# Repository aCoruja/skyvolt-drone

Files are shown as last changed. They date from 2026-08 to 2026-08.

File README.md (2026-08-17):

<div align="center">

# SkyVolt

**Drone medidor e fiscalizador de ambientes de alta e baixa energia**

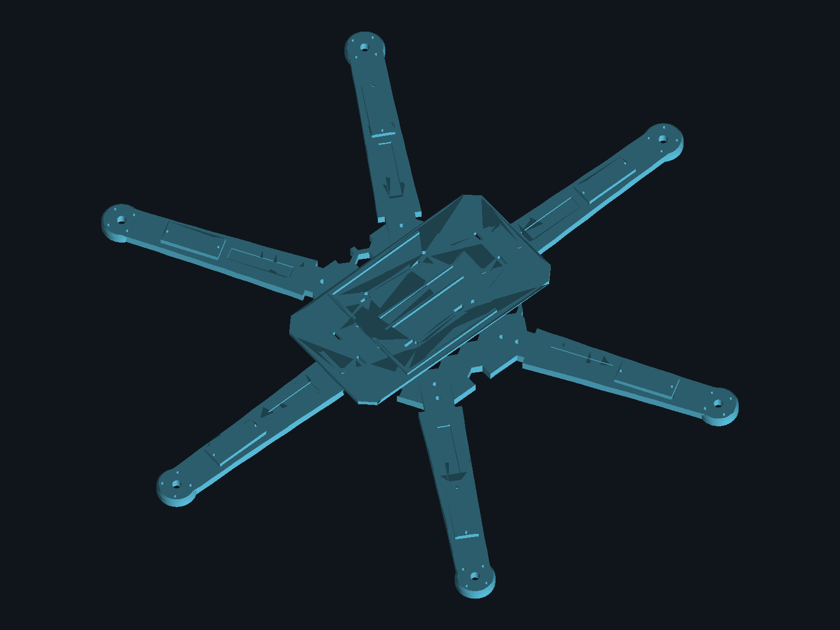
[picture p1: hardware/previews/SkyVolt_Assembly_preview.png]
Preview do hexacóptero SkyVolt montado


</div>

Hexacóptero de estrutura impressa em 3D cuja função principal é medir tensão e corrente elétrica em pontos de um ambiente controlado, classificar automaticamente o tipo de circuito (AC/DC, faixa de tensão) e reportar os dados a um aplicativo desktop de controle e monitoramento em tempo real via LoRa.

Projeto da disciplina 34943 — Desenvolvimento de Aplicações Computacionais (tema-base: Monitor de Consumo e Qualidade de Energia / Smart Grid), usando o SkyVolt como o protótipo físico opcional permitido pelo enunciado. Documento completo de requisitos, arquitetura e BOM em [`docs/SkyVolt_Documento.pdf`](docs/SkyVolt_Documento.pdf); Roadmap do semestre (14/08 a 02/12/2026) em [`ideias/roadmap.md`](ideias/roadmap.md); devolutivas das entregas em [`avaliacoes/`](avaliacoes/).

## Equipe

<!-- preencher com nome + usuário GitHub de cada integrante antes da entrega A1/1 — é critério de nota (governança/git) -->
- Matheus Dapper ([@aCoruja](https://github.com/aCoruja))
- _Vitória Aparecida Vendausen([@Viihvendausen](https://github.com/Viihvendausen)_

- _Sophia Gama de Moura ([@Sophthe141](https://github.com/Sophthe141))_

## Estrutura do repositório

```
README.md       este arquivo — visão geral, equipe e estado do projeto
docs/           documentos técnicos: requisitos, arquitetura e BOM (fonte .tex + PDF gerado),
                requisitos funcionais do app desktop
ideias/         planejamento e acompanhamento de ideias — o que o time PLANEJA fazer, semana a semana
avaliacoes/     devolutivas oficiais do professor por entrega — nota, feedback, pontos a corrigir
hardware/       projeto mecânico (CAD paramétrico FreeCAD, STL/STEP para impressão 3D)
  frame/        peças atuais — hub, braço (x6) e bandeja de eletrônica
  legacy/       versão anterior do frame (peça única), mantida como referência
  previews/     renders das peças
firmware/       código dos dois ESP32 (voo/FPV e telemetria/LoRa) — a especificar
app/            aplicativo desktop de controle e monitoramento — a especificar
notebooks/      prototipagem e análise de dados (calibração de sensores, protocolo LoRa, etc.)
```

`ideias/` e `avaliacoes/` são complementares: um documenta o planejamento, o outro o resultado real de cada entrega — mantidos junto ao roadmap para não perder o histórico de evolução da nota ao longo do semestre.

## Estado atual (Rev. 1.3 do documento)

- Requisitos, arquitetura e BOM fechados.
- Frame mecânico redesenhado em 3 peças modulares (hub + braço ×6 + bandeja de eletrônica), validado para impressora de mesa 220×220mm, motor brushless RS1606 3300KV com verificação de empuxo e autonomia.
- Firmware, aplicativo desktop e carcaças dos efetuadores ainda não iniciados — ver Seção 8 (Pendências) do documento.

## Peças (impressão 3D)

Gerado pelo script paramétrico [`skyvolt_frame.py`](hardware/frame/skyvolt_frame.py) (FreeCAD). Arquivos `.stl`/`.step`/`.FCStd` em [`hardware/frame/`](hardware/frame/).

<div align="center">
<table>
<tr>
<td align="center" width="33%">
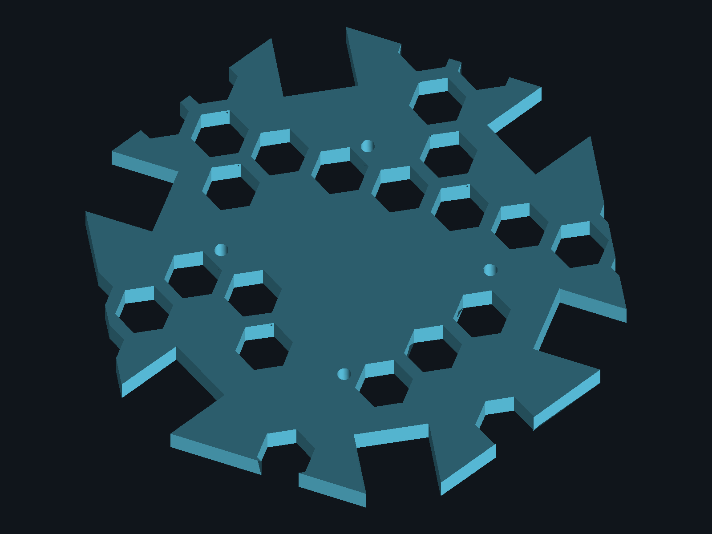
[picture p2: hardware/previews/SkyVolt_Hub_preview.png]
<br>
<b>Hub</b> — 1× — 129,6×121,2mm
</td>
<td align="center" width="33%">
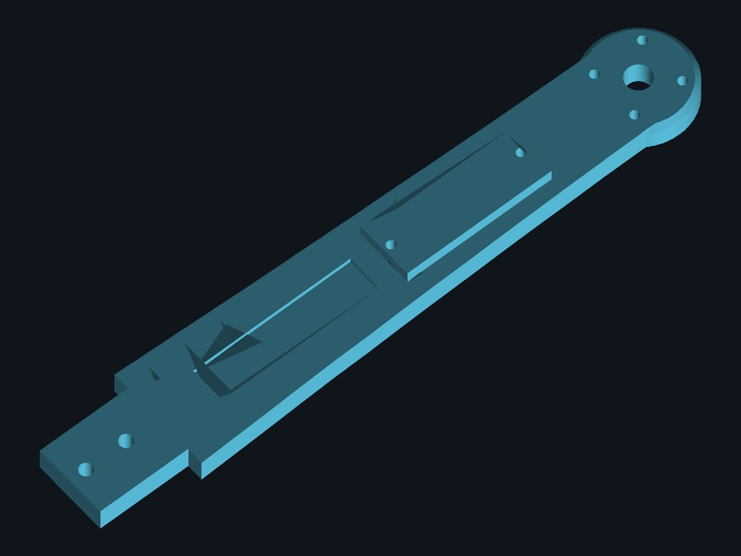
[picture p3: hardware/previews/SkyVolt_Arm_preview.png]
<br>
<b>Braço</b> — 6× — 154×26mm
</td>
<td align="center" width="33%">
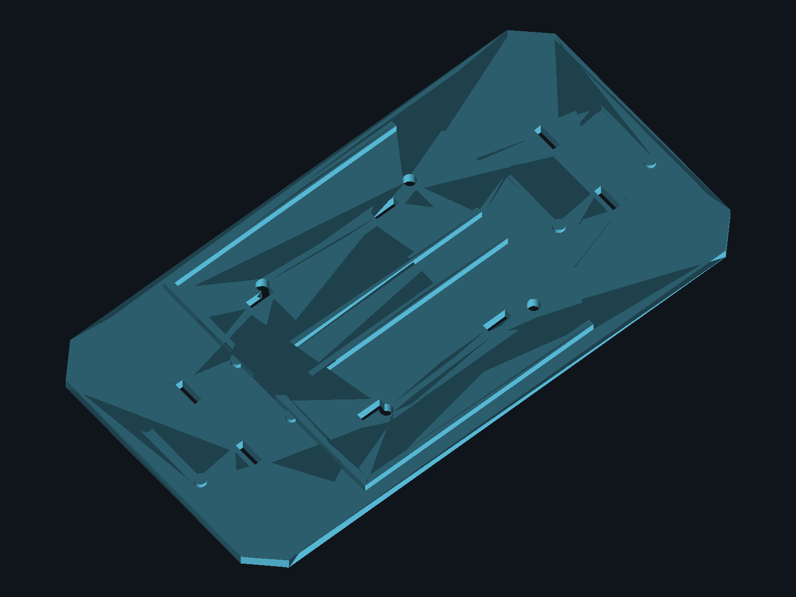
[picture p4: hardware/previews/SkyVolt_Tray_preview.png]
<br>
<b>Bandeja de eletrônica</b> — 1× — 150×80mm
</td>
</tr>
</table>
</div>

Todas as peças cabem numa mesa de impressão de 220×220mm. Hub e braço se unem por encaixe lingueta/rasgo + 2 parafusos M3 por junta; motor RS1606 3300KV (pad 12×12mm/4×M2); braço já sai com base de fixação para servo SG90.

## Utilização de IA

A utilização de IA foi realizada de forma educativa e colaborativa, com fins de estudo. A ferramenta não foi utilizada para resolver os problemas sem a aplicação de raciocínio lógico e compreensão por parte dos autores.

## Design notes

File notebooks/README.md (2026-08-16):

# Notebooks

Prototipagem e análise exploratória que não pertence ao firmware/app final: calibração de sensores (clamp de corrente, EMF, Hall/shunt), validação do protocolo de mensagens LoRa, análise de dados de bancada do motor/hélice, etc.

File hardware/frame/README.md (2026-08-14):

# Frame — peças atuais (Rev. 1.3)

<div align="center">
Montagem do frame SkyVolt
</div>

3 peças impressas separadamente, todas dentro da mesa de impressão de 220×220mm:

| Peça | Arquivo | Qtd | Dimensões |
|---|---|---|---|
| Hub | `SkyVolt_Hub.stl` | 1 | 129,6×121,2mm |
| Braço | `SkyVolt_Arm.stl` | 6 | 154×26mm |
| Bandeja de eletrônica | `SkyVolt_Tray.stl` | 1 | 150×80mm |

Gerado pelo script paramétrico `skyvolt_frame.py` (FreeCAD, `freecad.cmd skyvolt_frame.py`). `SkyVolt_Assembly_Preview.*` é só visualização (hub + 6 braços + bandeja posicionados), não é peça de impressão.

Hub e braço se unem por encaixe lingueta/rasgo + 2 parafusos M3 por junta. Motor: RS1606 3300KV, pad com padrão de furação 12×12mm/4×M2 (assumido para a classe do motor — confirmar contra datasheet real antes de imprimir em lote, ver Seção 8 do documento). Braço já sai com base de fixação para servo SG90 (M2, 32,5mm de espaçamento). Bandeja carrega 2×ESP32-S3 (trilho dimensionado para o footprint oficial 70×28mm) e 2×módulo LoRa (baia genérica por abraçadeira, footprint do módulo ainda não confirmado).

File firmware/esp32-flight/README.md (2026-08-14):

# ESP32 #1 — Voo / FPV

Responsável por vídeo de navegação (FPV) e comandos de voo via WiFi, baixa latência. Troca heartbeat por fio com o ESP32 #2 (telemetria/supervisor de segurança).

Código ainda não iniciado — ver Seção 4.3 e Seção 8 (Pendências) de `docs/SkyVolt_Documento.pdf`.

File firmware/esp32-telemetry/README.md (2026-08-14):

# ESP32 #2 — Telemetria / LoRa / Supervisor de segurança

Responsável pela telemetria de sensores via LoRa (tensão, corrente, classificação AC/DC, modo utilizado) e pela máquina de failsafe. Câmera e fonte de energia independentes do ESP32 #1.

Código ainda não iniciado — ver Seção 4.3 e Seção 8 (Pendências) de `docs/SkyVolt_Documento.pdf`.

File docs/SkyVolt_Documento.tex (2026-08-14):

\documentclass[11pt,a4paper]{article}

% ---------- PACOTES ----------
\usepackage[utf8]{inputenc}
\usepackage[T1]{fontenc}
\usepackage[brazilian]{babel}
\usepackage{lmodern}
\usepackage[a4paper,margin=2.3cm,top=2.6cm,bottom=2.8cm,headheight=22pt]{geometry}
\usepackage{xcolor}
\usepackage{colortbl}
\usepackage{booktabs}
\usepackage{longtable}
\usepackage{array}
\usepackage{tikz}
\usepackage{titlesec}
\usepackage{enumitem}
\usepackage{fancyhdr}
\usepackage{microtype}
\usepackage{hyperref}
\usepackage{textcomp}

% ---------- PALETA ----------
\definecolor{voltnavy}{HTML}{10151B}
\definecolor{voltcyan}{HTML}{1F6F8F}
\definecolor{voltcyanlight}{HTML}{5BC2E0}
\definecolor{voltcopper}{HTML}{B5652F}
\definecolor{voltamber}{HTML}{9A640C}
\definecolor{voltamberbg}{HTML}{F3E6CD}
\definecolor{voltok}{HTML}{2E6B4C}
\definecolor{voltokbg}{HTML}{DFEEE6}
\definecolor{voltpending}{HTML}{5B5F82}
\definecolor{voltgray}{HTML}{4D5A63}
\definecolor{voltrule}{HTML}{CDD4D9}
\definecolor{voltbandbg}{HTML}{EEF1F2}

\hypersetup{
  colorlinks=true,
  linkcolor=voltcyan,
  urlcolor=voltcyan,
  citecolor=voltcyan,
  pdftitle={SkyVolt - Documento de Requisitos, Arquitetura e BOM},
  pdfsubject={Drone medidor e fiscalizador de ambientes de alta e baixa energia}
}

% ---------- TIPOGRAFIA DE SEÇÕES ----------
\titleformat{\section}
  {\Large\bfseries\color{voltcyan}}
  {\thesection}{0.6em}{}
\titlespacing*{\section}{0pt}{1.6em}{0.9em}

\titleformat{\subsection}
  {\large\bfseries\color{voltcopper}}
  {\thesubsection}{0.6em}{}
\titlespacing*{\subsection}{0pt}{1.2em}{0.6em}

\renewcommand{\contentsname}{Sumário}

% ---------- CABEÇALHO/RODAPÉ ----------
\pagestyle{fancy}
\fancyhf{}
\renewcommand{\headrulewidth}{0.4pt}
\renewcommand{\headrule}{\hbox to\headwidth{\color{voltrule}\leaders\hrule height \headrulewidth\hfill}}
\fancyhead[L]{\footnotesize\ttfamily\color{voltgray} SkyVolt}
\fancyhead[R]{\footnotesize\ttfamily\color{voltgray} Requisitos \& Arquitetura}
\fancyfoot[C]{\footnotesize\ttfamily\color{voltgray} \thepage}

% ---------- COMANDOS AUXILIARES ----------
\newcommand{\specline}[2]{{\ttfamily\footnotesize\color{voltcyanlight}#1}\hfill{\normalsize\color{white}#2}\\[0.4em]}
\newcommand{\statusok}{\textcolor{voltok}{\textbf{decidido}}}
\newcommand{\statuspend}{\textcolor{voltpending}{\textbf{pendente}}}
\newcommand{\statushaz}{\textcolor{voltamber}{\textbf{limitação}}}
\newcommand{\pesq}{\textsuperscript{\textdagger}}

% caixa de destaque sem depender de tcolorbox
\newcommand{\aviso}[2]{%
  \par\noindent\colorbox{voltamberbg}{%
    \begin{minipage}{\dimexpr\linewidth-2\fboxsep\relax}
      \vspace{0.3em}
      \textcolor{voltamber}{\textbf{#1}} #2
      \vspace{0.3em}
    \end{minipage}%
  }\par\vspace{1em}
}

\newcommand{\destaque}[2]{%
  \par\noindent\colorbox{voltbandbg}{%
    \begin{minipage}{\dimexpr\linewidth-2\fboxsep\relax}
      \vspace{0.3em}
      \textcolor{voltcyan}{\textbf{#1}} #2
      \vspace{0.3em}
    \end{minipage}%
  }\par\vspace{1em}
}

\setlength{\parskip}{0.55em}
\setlength{\parindent}{0pt}

\begin{document}

% =====================================================
% CAPA
% =====================================================
\begin{titlepage}
\pagecolor{voltnavy}
\color{white}
\thispagestyle{empty}

\begin{center}
\vspace*{0.6cm}
{\ttfamily\small\color{voltcyanlight} DOCUMENTO DE REQUISITOS, ARQUITETURA \& BOM \;\textbullet\; REV.\ 1.3}

\vspace{1.6cm}

\begin{tikzpicture}[scale=1.0]
  \foreach \a in {0,60,...,300} {
    \draw[voltcyanlight!55!white, line width=0.7pt] (0,0) -- (\a:2.15);
    \filldraw[voltnavy, draw=voltcyanlight!75!white, line width=0.8pt] (\a:2.15) circle (3.1pt);
  }
  \filldraw[voltnavy, draw=white, line width=1pt] (0,0) circle (7pt);

  % efetuador — plugue (lateral, ciano)
  \draw[voltcyanlight, line width=1.1pt] (0,0) -- (0:1.35);
  \filldraw[voltcyanlight] (0.1,1.2) rectangle (0.42,1.5);
  \node[anchor=west, voltcyanlight, font=\ttfamily\tiny] at (0.9,2.3) {plugue 3 pinos};
  \draw[voltcyanlight, line width=0.4pt] (0.42,1.4) -- (0.85,2.25);

  % efetuador — garra de campo (âmbar)
  \draw[voltamber!70!voltcyanlight, line width=1.1pt] (0,0) -- (215:1.3);
  \draw[voltamber!60!white, line width=1.3pt] (215:1.3) circle (4.4pt);
  \node[anchor=east, voltamber!60!white, font=\ttfamily\tiny] at (-2.0,-1.55) {garra de campo};
  \draw[voltamber!60!white, line width=0.4pt] (215:1.3) -- (-2.0,-1.5);

  % efetuador — garra de contato (cobre)
  \draw[voltcopper!85!white, line width=1.1pt] (0,0) -- (145:1.3);
  \filldraw[voltcopper!85!white] (145:1.3) circle (4.4pt);
  \node[anchor=east, voltcopper!85!white, font=\ttfamily\tiny] at (-2.0,1.55) {garra de contato};
  \draw[voltcopper!85!white, line width=0.4pt] (145:1.3) -- (-2.0,1.5);
\end{tikzpicture}

\vspace{0.9cm}

{\ttfamily\footnotesize\color{voltcyanlight} NOME DE PROJETO}\\[0.35em]
{\fontsize{42}{46}\selectfont\bfseries SkyVolt}\\[0.55em]
{\normalsize\itshape\color{white!70!voltnavy} Drone medidor e fiscalizador de ambientes de alta e baixa energia}

\vspace{1.3cm}

\begin{minipage}{10.6cm}
\specline{CURSO}{Desenvolvimento de Aplicações Desktop}
\specline{DATA}{14/08/2026}
\specline{REVISÃO}{1.3}
\specline{IMPRESSÃO 3D}{Fornecida pela faculdade — sem custo ao projeto}
\specline{TETO DE ORÇAMENTO (EQUIPAMENTO)}{R\$~2.000,00}
\specline{GASTO MÉDIO ESTIMADO (BOM)}{R\$~1.903,80}
\specline{ELABORADO POR}{\_\_\_\_\_\_\_\_\_\_\_\_\_\_\_\_\_\_\_\_\_\_\_\_\_\_\_\_}
\end{minipage}

\vfill
{\ttfamily\tiny\color{voltcyanlight!70!white} vista superior esquemática — três efetuadores em posições distintas do drone}
\vspace{0.4cm}
\end{center}
\end{titlepage}

\pagecolor{white}
\color{black}

% =====================================================
% SUMÁRIO
% =====================================================
\thispagestyle{empty}
\tableofcontents
\newpage

% =====================================================
% 1. VISÃO GERAL
% =====================================================
\section{Visão geral do projeto}

O SkyVolt é um hexacóptero de estrutura impressa em 3D (impressora fornecida pela faculdade, sem custo ao projeto) cuja função principal é medir tensão e corrente elétrica em pontos de um ambiente controlado, classificando automaticamente o tipo de circuito e reportando os dados a um aplicativo desktop de controle e monitoramento.

\destaque{Princípio orientador de escopo:}{a medição é a função \emph{core} do projeto; a plataforma voadora é secundária. Sempre que o orçamento ou o prazo exigirem corte de escopo, a prioridade recai sobre manter a função de medição íntegra, simplificando o drone antes de simplificar o sensoriamento.}

\textbf{Papel do aplicativo desktop} (entregável central da disciplina): estação de controle e monitoramento, recebendo telemetria em tempo real via LoRa, exibindo tensão, corrente, temperatura e classificação num painel, mantendo histórico local de medições e emitindo alertas configuráveis.

\textbf{Faixa elétrica do escopo:} circuitos AC de até 220V (padrão residencial/tomada) e circuitos DC sempre $\leq$100V (restrição de projeto). Ambientes acima de 220V estão fora de escopo pelo risco de arco elétrico.

% =====================================================
% 2. REQUISITOS FUNCIONAIS
% =====================================================
\section{Requisitos funcionais}

\begin{longtable}{@{}p{1.6cm}p{12.6cm}@{}}
\toprule
\textbf{ID} & \textbf{Requisito} \\
\midrule
\endhead
\bottomrule
\endfoot
RF01 & Medir tensão AC/DC entre 5V e 220V, conforme o modo de contato disponível. \\
RF02 & Medir corrente elétrica, por contato direto ou por indução (clamp sem contato). \\
RF03 & Estimar potência dissipada (Lei de Joule) a partir de leitura térmica. \\
RF04 & Transmitir telemetria de sensores (tensão, corrente, classificação AC/DC, modo utilizado) via LoRa até a estação base. \\
RF05 & Exibir os dados recebidos em tempo real no aplicativo desktop (dashboard). \\
RF06 & Registrar histórico de medições localmente (SD/flash) e sincronizar com o app quando o link permitir. \\
RF07 & Posicionar um entre três efetuadores — garra de campo, garra de contato ou plugue de 3 pinos — no ponto de medição, conforme o modo classificado. \\
RF08 & Emitir alerta no aplicativo quando valores excederem limites configuráveis. \\
RF09 & Transmitir vídeo de navegação (FPV) e comandos de voo via WiFi, com baixa latência. \\
RF10 & Classificar automaticamente o alvo (conector padrão / campo AC $\geq$100V / contato $<$100V ou DC) por reconhecimento sem contato, a uma distância de stand-off calibrada, sem informação prévia do operador. \\
RF11 & Executar rotina autônoma de segurança ao detectar qualquer falha, navegando até uma zona segura pré-estabelecida por marcador visual. \\
\end{longtable}

% =====================================================
% 3. RNF
% =====================================================
\section{Requisitos não-funcionais e restrições}

\begin{longtable}{@{}p{1.9cm}p{12.3cm}@{}}
\toprule
\textbf{ID} & \textbf{Restrição} \\
\midrule
\endhead
\bottomrule
\endfoot
RNF01 & Teto de orçamento: R\$~2.000 para equipamento. Impressão 3D fornecida pela faculdade (acordo com o coordenador), sem custo ao projeto. \\
RNF02 & Isolamento galvânico entre o circuito medido (até 220V) e a eletrônica de controle; hardware do modo contato dimensionado para tolerar até 220V mesmo em caso de erro de classificação (defesa em profundidade). \\
RNF03 & Domínios de energia separados — propulsão, eletrônica/medição e supervisor de segurança — para evitar falha compartilhada. \\
RNF04 & Tolerância de posicionamento de $\pm$1,5cm por eixo na abordagem manual, compensada por folga mecânica e funil de captura. \\
RNF05 & Autonomia mínima de voo de 8 a 12 minutos por missão. \\
RNF06 & Escopo elétrico fixo: DC sempre $\leq$100V; AC até 220V. \\
RNF07 & Redundância mínima de propulsão: tolerância a falha de 1 motor entre 6 (hexacóptero). \\
\end{longtable}

% =====================================================
% 4. ARQUITETURA
% =====================================================
\section{Arquitetura do sistema}

\subsection{Estrutura e propulsão \normalfont\statusok}

Estrutura impressa em impressora 3D fornecida pela faculdade (acordo com o coordenador, sem custo ao orçamento). Configuração \textbf{hexacóptero} (6 motores), escolhida como meio-termo entre custo e redundância mecânica: tolera a perda de 1 motor sem queda imediata, ao contrário de um quadricóptero, e custa/pesa menos que o octocóptero originalmente cogitado.

\textbf{Motores brushless RS1606 3300KV} (hélice 3", ESC brushless dedicado por motor) — decisão revisada na Rev.~1.2 a partir do fechamento da verificação de empuxo abaixo. A escolha original por motor de escova (Rev.~1.1) foi descartada: motor de escova compatível com o porte do frame não sustenta o peso estimado da aeronave. Motor brushless exige comutação eletrônica trifásica — um driver ponte-H simples (ex.\ L293D), adequado para motor de escova, \emph{não} serve para acionar motor brushless; por isso cada motor tem um ESC dedicado no BOM (Seção~6.1).

\destaque{Verificação de empuxo (thrust-to-weight) — fechada:}{peso bruto máximo estimado (cenário pessimista, todos os componentes) $\approx$1.110g — atualizado na Rev.~1.3 com o peso real da estrutura, obtido do CAD paramétrico (FreeCAD) em vez de estimativa de densidade: 264g para hub + 6 braços + bandeja de eletrônica (100\% infill PETG). Motor RS1606~3300KV entrega até 875g de empuxo por motor com hélice de 4" (dado de fabricante, 23,7A/398W a 4S) — TWR$\approx$4,7. Com hélice de 3" (empuxo reduzido, estimado por teoria de disco atuador na ausência de bancada publicada para esse par), TWR estimado $\approx$2,7--3,5, ainda acima do mínimo seguro de 1,5--2,0. A hélice de 3" foi escolhida no lugar da de 4" para também trazer a autonomia para dentro da janela de RNF05 sem alterar a bateria — ver Seção~4.4.}

\textbf{Estrutura modular (Rev.~1.3):} o chassi foi redesenhado em 3 peças impressas separadamente — \textbf{hub} (129,6$\times$121,2mm), \textbf{braço} (154$\times$26mm, imprimir $\times$6) e \textbf{bandeja de eletrônica} (150$\times$80mm) — todas dentro da mesa de impressão de 220$\times$220mm do equipamento disponível (o frame original de peça única, 330$\times$290mm, não cabia). Braço e hub se unem por encaixe lingueta/rasgo (tenon/mortise) reforçado com 2 parafusos M3 por junta (12 no total), mais resistente à flexão do que um encaixe topo-a-topo só parafusado. Pad do motor dimensionado para o RS1606~3300KV: padrão de furação quadrado 12$\times$12mm, 4$\times$M2 — \emph{padrão típico da classe 1606, não confirmado contra o datasheet oficial do fabricante (ver Seção~8)}.

\subsection{Sistema de medição — função principal \normalfont\statusok}

Três efetuadores especializados, cada um resolvendo um modo de medição diferente:

\begin{itemize}[itemsep=2pt]
  \item \textbf{Garra de campo} (servo, retrátil) — medição sem contato, para AC $\geq$100V.
  \item \textbf{Garra de contato} (servo) — contato direto, para $<$100V ou DC.
  \item \textbf{Plugue de 3 pinos} (padrão NBR~14136), montado na lateral do drone, com funil/guia de captura impresso e ponta modular para adaptadores de outros tipos de tomada.
\end{itemize}

A escolha do efetuador segue uma triagem em três etapas: aproximação até uma distância de stand-off calibrada, reconhecimento sem contato (sensor de campo EMF + câmera térmica) e classificação — tudo decidido pelo próprio sistema, sem informação prévia do operador sobre o circuito, conforme resumido na tabela a seguir.

\textbf{Fixação física (Rev.~1.3):} os 6 braços do frame já saem impressos com base de fixação para servo SG90 (furação M2, espaçamento 32,5mm, padrão de mercado) — os 3 braços efetuadores usam essa base para a garra/plugue; os outros 3 ficam com a base livre, sem custo extra relevante de peso ou impressão. Carcaça específica de cada efetuador (garra de campo, garra de contato, funil do plugue NBR~14136) ainda não foi desenhada — ver Seção~8.

\textbf{Árvore de triagem do sistema de medição}\\[0.4em]
\begin{longtable}{@{}p{4.6cm}p{4.6cm}p{5cm}@{}}
\toprule
\textbf{Condição} & \textbf{Modo escolhido} & \textbf{Precisão obtida} \\
\midrule
\endfirsthead
\toprule
\textbf{Condição} & \textbf{Modo escolhido} & \textbf{Precisão obtida} \\
\midrule
\endhead
\bottomrule
\endfoot
Conector padrão visível & Modo A — plugue 3 pinos & Tensão e corrente exatas, seguro em qualquer tensão do escopo \\
Sinal AC no campo, $\geq$100V & Modo B — campo (clamp) & Corrente exata; tensão em faixa (limitação física) \\
Sinal AC no campo, $<$100V & Modo B — contato & Tensão e corrente exatas, isolado até 220V \\
Sem sinal AC (DC, $\leq$100V garantido) & Modo B — contato & Tensão e corrente exatas \\
\end{longtable}

\subsection{Comunicação e redundância \normalfont\statusok}

Dois rádios com papéis distintos, mapeados a dois microcontroladores independentes:

\begin{itemize}[itemsep=2pt]
  \item \textbf{WiFi (ESP32~\#1):} vídeo de navegação (FPV) + comandos de voo — baixa latência.
  \item \textbf{LoRa (ESP32~\#2):} telemetria de sensores — pacotes pequenos, atua também como \textbf{supervisor de segurança}.
\end{itemize}

Os dois ESP32 trocam um heartbeat por fio (independente de rádio). O ESP32~\#2 tem câmera própria dedicada e fonte de energia independente — nenhuma dependência compartilhada com o ESP32~\#1 que pudesse derrubar os dois juntos.

\textbf{Máquina de failsafe:} qualquer problema detectado (perda de link, bateria crítica, falha de sensor/IMU, efetuador travado) aciona a mesma rotina — se engajado com o alvo, desengate controlado e lento primeiro; em seguida, navegação autônoma via marcador visual até a zona segura pré-estabelecida, pouso com motores desarmados e efetuador inerte.

\subsection{Energia \normalfont\statusok}

\begin{longtable}{@{}p{3cm}p{4.3cm}p{3cm}p{5cm}@{}}
\toprule
\textbf{Domínio} & \textbf{Química/fonte} & \textbf{Proteção} & \textbf{Observação} \\
\midrule
\endhead
\bottomrule
\endfoot
Propulsão & Li-ion alta descarga (18650/21700) & BMS obrigatório & Mais seguro que LiPo em queda perto de circuito energizado \\
Eletrônica/medição & Domínio próprio, separado da propulsão & Isolamento do sag de tensão & Evita brownout do ESP32 durante o contato \\
Supervisor (ESP32~\#2) & Fonte independente dedicada & — & Sobrevive a falha da bateria de eletrônica \\
\end{longtable}

Autonomia alvo por missão: 8 a 12 minutos (decolagem $\rightarrow$ aproximação $\rightarrow$ medição $\rightarrow$ retorno $\rightarrow$ pouso).

\destaque{Estimativa de autonomia (atualizada na Rev.~1.3 com o peso real da estrutura):}{motor RS1606~3300KV + hélice~3", bateria de propulsão mantida sem alteração (4$\times$ células 21700 alta descarga, 4,2Ah, 4S1P, $\approx$48,4Wh utilizáveis). Potência em hover estimada em $\approx$277W (era 248W na Rev.~1.2, antes do peso real do CAD) $\rightarrow$ autonomia $\approx$10,5 minutos, ainda dentro da janela de RNF05 mas com menos folga que antes. Estimativa apoiada em extrapolação de curva de eficiência de motor similar (sem bancada real do par motor+hélice escolhido) — ver pendência na Seção~8.}

\subsection{Iluminação \normalfont\statusok}

LED difuso, para a câmera normal de navegação (FPV) em ambientes escuros — difuso em vez de focado para evitar reflexo em contatos metálicos. Controle manual, ligado/desligado pelo piloto.

\subsection{PCBs \normalfont\statusok}

Placas perfuradas de 1 camada, soldadas à mão, divididas por domínio funcional: potência/propulsão, ESP32~\#1, ESP32~\#2, sensores de medição (duas metades fisicamente separadas — lado perigoso e lado seguro, isolados por optoacoplador certificado) e adaptador do Modo~A. Sem plano de terra, a separação física da placa de potência e o aterramento em estrela ganham ainda mais importância para reduzir ruído de chaveamento contaminando a leitura.

\textbf{Fixação física (Rev.~1.3):} bandeja impressa dedicada (150$\times$80mm), aparafusada nos 4 furos de coluna do hub por espaçadores/standoffs — carrega os 2 ESP32-S3 em trilhos dimensionados para o footprint oficial do DevKitC-1 (70$\times$28mm) e os 2 módulos LoRa em baia genérica com abraçadeira (footprint do módulo real ainda não confirmado — ver Seção~8).

% =====================================================
% 5. RISCOS
% =====================================================
\section{Riscos e limitações conhecidas}

\begin{longtable}{@{}p{0.7cm}p{9.6cm}p{3.4cm}@{}}
\toprule
\textbf{\#} & \textbf{Risco / limitação} & \textbf{Status} \\
\midrule
\endhead
\bottomrule
\endfoot
1 & Cenário máximo (R\$~2.674,70) ainda ultrapassa o teto de R\$~2.000 caso cotações finais batam no topo da faixa. & \statushaz \\
2 & Redundância de motor reduzida (hexacóptero vs.\ octocóptero original). & troca aceita \\
3 & Empuxo e autonomia do par motor RS1606~3300KV + hélice~3" baseados em extrapolação de curva de eficiência, não em bancada real do par escolhido (TWR$\approx$2,7--3,5; autonomia $\approx$10,5min). & mitigado parcial \\
4 & Tensão exata não garantida em pontos sem conector acima de 100V. & \statushaz \\
5 & Interferência eletromagnética do próprio circuito medido no link WiFi. & \statushaz \\
6 & Contato físico em até 220V exige isolamento rigoroso. & \statusok \\
7 & Bateria danificada em queda perto de circuito energizado — risco composto. & \statusok \\
8 & Falha compartilhada de bateria de eletrônica derrubando os dois ESP32. & \statusok \\
9 & Falha compartilhada de câmera entre ESP32~\#1 e \#2. & \statusok \\
10 & Ausência de plano de terra (PCB 1 camada) aumenta suscetibilidade a ruído. & mitigado parcial \\
11 & Precisão do encaixe do plugue incompatível com tolerância de pilotagem manual. & \statusok \\
12 & Drone preso ao alvo indefinidamente se o link cair durante contato. & \statusok \\
\end{longtable}

% =====================================================
% 6. BOM
% =====================================================
\section{Levantamento de custos (BOM)}

Os valores abaixo combinam cotações diretas de mercado brasileiro (agosto/2026, marcadas com \pesq) e estimativas de engenharia para itens sem padronização de preço (componentes equivalentes, faixa de mercado observada). Colunas \textbf{Mín.}, \textbf{Méd.} e \textbf{Máx.} representam o cenário mais barato, o cenário médio esperado e o cenário mais caro plausível por item.

\subsection{Estrutura e propulsão}

\begin{longtable}{@{}p{5.4cm}p{0.9cm}p{1.7cm}p{1.7cm}p{1.7cm}p{2.1cm}@{}}
\toprule
\textbf{Item} & \textbf{Qtd} & \textbf{Mín.\ un.} & \textbf{Méd.\ un.} & \textbf{Máx.\ un.} & \textbf{Total (méd.)} \\
\midrule
\endhead
\bottomrule
\endfoot
Motor brushless RS1606 3300KV & 6 & R\$~35,00 & R\$~50,00 & R\$~70,00 & R\$~300,00 \\
ESC brushless 30A (dedicado por motor) & 6 & R\$~18,00 & R\$~25,00 & R\$~35,00 & R\$~150,00 \\
Kit hélices 3" (jogo + reservas) & 1 & R\$~20,00 & R\$~35,00 & R\$~50,00 & R\$~35,00 \\
Filamento PLA/PETG (chassi) & 1 & R\$~30,00 & R\$~45,00 & R\$~60,00 & R\$~45,00 \\
\midrule
\multicolumn{5}{r}{\textbf{Subtotal — Mín.\ R\$~368,00 \quad Méd.\ R\$~530,00 \quad Máx.\ R\$~740,00}} & \\
\end{longtable}

\subsection{Controle e comunicação}

\begin{longtable}{@{}p{5.4cm}p{0.9cm}p{1.7cm}p{1.7cm}p{1.7cm}p{2.1cm}@{}}
\toprule
\textbf{Item} & \textbf{Qtd} & \textbf{Mín.\ un.} & \textbf{Méd.\ un.} & \textbf{Máx.\ un.} & \textbf{Total (méd.)} \\
\midrule
\endhead
\bottomrule
\endfoot
ESP32-S3 (módulo dev)\pesq & 2 & R\$~27,34 & R\$~45,00 & R\$~74,80 & R\$~90,00 \\
Módulo LoRa SX1276/RFM95\pesq & 2 & R\$~70,00 & R\$~79,90 & R\$~90,00 & R\$~159,80 \\
\midrule
\multicolumn{5}{r}{\textbf{Subtotal — Mín.\ R\$~194,68 \quad Méd.\ R\$~249,80 \quad Máx.\ R\$~329,60}} & \\
\end{longtable}

\subsection{Câmeras}

\begin{longtable}{@{}p{5.4cm}p{0.9cm}p{1.7cm}p{1.7cm}p{1.7cm}p{2.1cm}@{}}
\toprule
\textbf{Item} & \textbf{Qtd} & \textbf{Mín.\ un.} & \textbf{Méd.\ un.} & \textbf{Máx.\ un.} & \textbf{Total (méd.)} \\
\midrule
\endhead
\bottomrule
\endfoot
Câmera térmica MLX90640\pesq & 1 & R\$~180,00 & R\$~260,00 & R\$~400,00 & R\$~260,00 \\
Câmera FPV + VTX (navegação) & 1 & R\$~90,00 & R\$~150,00 & R\$~250,00 & R\$~150,00 \\
Câmera dedicada ESP32~\#2 (OV2640)\pesq & 1 & R\$~25,00 & R\$~40,00 & R\$~55,00 & R\$~40,00 \\
\midrule
\multicolumn{5}{r}{\textbf{Subtotal — Mín.\ R\$~295,00 \quad Méd.\ R\$~450,00 \quad Máx.\ R\$~705,00}} & \\
\end{longtable}

\subsection{Sensores de medição}

\begin{longtable}{@{}p{5.4cm}p{0.9cm}p{1.7cm}p{1.7cm}p{1.7cm}p{2.1cm}@{}}
\toprule
\textbf{Item} & \textbf{Qtd} & \textbf{Mín.\ un.} & \textbf{Méd.\ un.} & \textbf{Máx.\ un.} & \textbf{Total (méd.)} \\
\midrule
\endhead
\bottomrule
\endfoot
Sensor de campo EMF (não-contato) & 1 & R\$~30,00 & R\$~50,00 & R\$~70,00 & R\$~50,00 \\
Clamp de corrente SCT-013\pesq & 1 & R\$~47,50 & R\$~55,00 & R\$~63,10 & R\$~55,00 \\
Sensor Hall/shunt de contato (ACS712) & 1 & R\$~15,00 & R\$~20,00 & R\$~28,00 & R\$~20,00 \\
Optoacoplador PC817 (módulo)\pesq & 2 & R\$~7,00 & R\$~8,00 & R\$~12,00 & R\$~16,00 \\
Fusível/PTC + proteção & 1 & R\$~5,00 & R\$~10,00 & R\$~15,00 & R\$~10,00 \\
\midrule
\multicolumn{5}{r}{\textbf{Subtotal — Mín.\ R\$~111,50 \quad Méd.\ R\$~151,00 \quad Máx.\ R\$~200,10}} & \\
\end{longtable}

\subsection{Efetuadores}

\begin{longtable}{@{}p{5.4cm}p{0.9cm}p{1.7cm}p{1.7cm}p{1.7cm}p{2.1cm}@{}}
\toprule
\textbf{Item} & \textbf{Qtd} & \textbf{Mín.\ un.} & \textbf{Méd.\ un.} & \textbf{Máx.\ un.} & \textbf{Total (méd.)} \\
\midrule
\endhead
\bottomrule
\endfoot
Micro servo (SG90 ou equiv.)\pesq & 3 & R\$~16,90 & R\$~19,00 & R\$~25,00 & R\$~57,00 \\
Plugue NBR~14136 + adaptadores & 1 & R\$~15,00 & R\$~25,00 & R\$~35,00 & R\$~25,00 \\
Funil de captura + filamento extra & 1 & R\$~10,00 & R\$~15,00 & R\$~20,00 & R\$~15,00 \\
Hardware das garras (dobradiças, fixação) & 1 & R\$~20,00 & R\$~35,00 & R\$~50,00 & R\$~35,00 \\
\midrule
\multicolumn{5}{r}{\textbf{Subtotal — Mín.\ R\$~95,70 \quad Méd.\ R\$~132,00 \quad Máx.\ R\$~180,00}} & \\
\end{longtable}

\subsection{Energia}

\begin{longtable}{@{}p{5.4cm}p{0.9cm}p{1.7cm}p{1.7cm}p{1.7cm}p{2.1cm}@{}}
\toprule
\textbf{Item} & \textbf{Qtd} & \textbf{Mín.\ un.} & \textbf{Méd.\ un.} & \textbf{Máx.\ un.} & \textbf{Total (méd.)} \\
\midrule
\endhead
\bottomrule
\endfoot
Célula Li-ion 18650/21700 alta descarga\pesq & 4 & R\$~25,00 & R\$~35,00 & R\$~45,00 & R\$~140,00 \\
BMS (pack propulsão) & 1 & R\$~25,00 & R\$~40,00 & R\$~60,00 & R\$~40,00 \\
Bateria eletrônica (domínio medição) & 1 & R\$~20,00 & R\$~30,00 & R\$~40,00 & R\$~30,00 \\
Bateria backup ESP32~\#2 & 1 & R\$~10,00 & R\$~17,00 & R\$~25,00 & R\$~17,00 \\
\midrule
\multicolumn{5}{r}{\textbf{Subtotal — Mín.\ R\$~155,00 \quad Méd.\ R\$~227,00 \quad Máx.\ R\$~305,00}} & \\
\end{longtable}

\subsection{Iluminação, PCB e montagem}

\begin{longtable}{@{}p{5.4cm}p{0.9cm}p{1.7cm}p{1.7cm}p{1.7cm}p{2.1cm}@{}}
\toprule
\textbf{Item} & \textbf{Qtd} & \textbf{Mín.\ un.} & \textbf{Méd.\ un.} & \textbf{Máx.\ un.} & \textbf{Total (méd.)} \\
\midrule
\endhead
\bottomrule
\endfoot
LED difuso + driver/resistor & 1 & R\$~10,00 & R\$~17,00 & R\$~25,00 & R\$~17,00 \\
Placa perfurada (protoboard) & 6 & R\$~8,00 & R\$~12,00 & R\$~15,00 & R\$~72,00 \\
Fios, conectores, solda, hardware geral & 1 & R\$~50,00 & R\$~75,00 & R\$~100,00 & R\$~75,00 \\
\midrule
\multicolumn{5}{r}{\textbf{Subtotal — Mín.\ R\$~108,00 \quad Méd.\ R\$~164,00 \quad Máx.\ R\$~215,00}} & \\
\end{longtable}

\subsection{Resumo geral e comparação com o orçamento}

\begin{longtable}{@{}p{6.5cm}p{2.3cm}p{2.3cm}p{2.3cm}@{}}
\toprule
\textbf{Categoria} & \textbf{Mín.} & \textbf{Méd.} & \textbf{Máx.} \\
\midrule
\endhead
\bottomrule
\endfoot
Estrutura e propulsão & R\$~368,00 & R\$~530,00 & R\$~740,00 \\
Controle e comunicação & R\$~194,68 & R\$~249,80 & R\$~329,60 \\
Câmeras & R\$~295,00 & R\$~450,00 & R\$~705,00 \\
Sensores de medição & R\$~111,50 & R\$~151,00 & R\$~200,10 \\
Efetuadores & R\$~95,70 & R\$~132,00 & R\$~180,00 \\
Energia & R\$~155,00 & R\$~227,00 & R\$~305,00 \\
Iluminação, PCB e montagem & R\$~108,00 & R\$~164,00 & R\$~215,00 \\
\midrule
\textbf{TOTAL DO PROJETO} & \textbf{R\$~1.327,88} & \textbf{R\$~1.903,80} & \textbf{R\$~2.674,70} \\
\end{longtable}

\destaque{Orçamento cabe no cenário provável, com folga reduzida:}{com o teto revisado para R\$~2.000,00 e a impressão 3D fora do orçamento (fornecida pela faculdade), tanto o cenário mínimo (R\$~1.327,88) quanto o médio (R\$~1.903,80) ficam dentro do teto, com folga de R\$~672,12 e R\$~96,20 respectivamente. A troca para motor brushless (Rev.~1.2) reduziu a folga do cenário médio de R\$~312,20 para R\$~96,20 — margem bem mais apertada que antes.}

\aviso{Risco remanescente — cenário máximo:}{o cenário mais caro (R\$~2.674,70) ainda ultrapassa o teto de R\$~2.000,00 em R\$~674,70 (era R\$~374,70 antes da troca de motor). O conjunto motor+ESC brushless (R\$~312 de oscilação combinada) passou a rivalizar com a câmera térmica MLX90640 (R\$~180 a R\$~400, variação de R\$~220) como maior fator de risco orçamentário, seguidos pela câmera FPV+VTX e pelo pack de energia. Cotação formal do motor/ESC antes da compra é recomendada dado o novo impacto no teto.}

% =====================================================
% 7. DECISÕES
% =====================================================
\section{Registro de decisões}

\begin{longtable}{@{}p{4.4cm}p{4.4cm}p{5.4cm}@{}}
\toprule
\textbf{Decisão} & \textbf{Alternativa considerada} & \textbf{Justificativa} \\
\midrule
\endhead
\bottomrule
\endfoot
Hexacóptero & Quadricóptero / octocóptero & Meio-termo entre custo e redundância de motor \\
Motor brushless RS1606~3300KV + hélice~3" & Motor de escova (decisão original, Rev.~1.1); motor brushless 2205/2207 & Verificação de TWR (peso pessimista $\approx$991g) mostrou que motor de escova não sustenta o peso; motor 2205/2207 sustenta com folga mas puxa corrente ($>$20A/motor) incompatível com a bateria do BOM; RS1606+hélice~3" fecha TWR seguro ($\approx$3--4$\times$) e autonomia $\approx$11,7min (RNF05) \\
Manter a bateria de propulsão original (4$\times$~21700 alta descarga, 4,2Ah) & Redimensionar a bateria para a nova autonomia & Evita retrabalho na célula já escolhida; hélice~3" (menos eficiente que 4") absorve o excesso de autonomia e traz o tempo de voo para dentro de 8--12min sem mexer na bateria \\
Frame em 3 peças modulares (hub + braço~$\times$6 + bandeja de eletrônica), encaixe lingueta/rasgo + parafuso M3 & Frame em peça única & Peça única (330$\times$290mm) não cabe na mesa de impressão de 220$\times$220mm disponível; encaixe lingueta/rasgo resiste a flexão melhor que topo-a-topo só parafusado \\
Bandeja de eletrônica separada, aparafusada no hub por standoffs & ESP32/LoRa direto no hub & Hub não tem área livre para 2$\times$ESP32-S3 (70$\times$28mm) + 2$\times$LoRa sem competir com o favo de mel e os braços; bandeja em segundo andar resolve o conflito de espaço \\
Base de servo (SG90) presente nos 6 braços, não só nos 3 efetuadores & Base só nos 3 braços efetuadores & Mantém a peça do braço única/intercambiável para impressão; custo de peso extra nos 3 braços sem efetuador é desprezível \\
Abordagem manual via FPV & Navegação autônoma completa & Reduz escopo de software; drone é secundário à medição \\
Três efetuadores especializados & Um único efetuador genérico & Cada modo de medição tem exigência física distinta \\
Triagem autônoma às cegas & Operador pré-define o modo & Exigência do projeto: sistema deve classificar sozinho \\
Li-ion 18650/21700 na propulsão & LiPo tradicional & Menor risco de incêndio em queda perto de circuito energizado \\
Dois domínios de bateria & Bateria única com BEC & Evita brownout do ESP32 durante o contato de medição \\
Dois ESP32 com papéis distintos & Um único ESP32 fazendo tudo & Redundância de rádio e supervisor de segurança independente \\
Navegação de emergência por marcador visual & Dead-reckoning puro & Mais robusto contra deriva; problema de visão contido a um alvo fixo \\
Placa de medição em duas metades separadas & Duas zonas na mesma placa & Isolamento físico real, independente da solda manual \\
PCB em protoboard (1 camada) & Fabricação profissional sob encomenda & Economia de orçamento e prazo \\
\end{longtable}

% =====================================================
% 8. PENDÊNCIAS
% =====================================================
\section{Pendências e trabalho futuro}

\begin{itemize}[itemsep=3pt]
  \item Validação em bancada real do motor RS1606~3300KV com hélice de 3" (empuxo e corrente em throttle parcial) — a autonomia estimada ($\approx$10,5min) usa extrapolação da curva de eficiência de outro motor, não dado medido do par escolhido.
  \item Confirmação do padrão de furação real do RS1606 (assumido 12$\times$12mm, 4$\times$M2 — padrão típico da classe 1606, não confirmado contra datasheet do fabricante) antes de imprimir o braço em lote.
  \item Confirmação do footprint real do módulo LoRa (SX1276/RFM95) para apertar o encaixe da bandeja de eletrônica — hoje é uma baia genérica com abraçadeira por falta de dado de fixação confirmado.
  \item Cotação formal do motor brushless RS1606~3300KV e do ESC dedicado — juntos, tornaram-se o maior fator de oscilação do orçamento (R\$~312 de variação combinada), reduzindo a folga do cenário médio para R\$~96,20.
  \item Peso da estrutura impressa (hub + 6 braços + bandeja) já confirmado por CAD real: 264g. Falta confirmar o peso real dos demais componentes (motor, ESC, bateria, eletrônica, sensores) contra a estimativa pessimista usada na verificação de empuxo ($\approx$1.110g no total).
  \item Fechamento do BOM com cotações formais (não estimativas) para os itens sem preço pesquisado.
  \item Cotação formal da câmera térmica MLX90640 antes das demais compras — é o item de maior risco de estourar o teto de R\$~2.000,00 no cenário máximo.
  \item Escolha de modelos específicos de sensor (clamp de corrente, sensor de campo EMF, sensor Hall/shunt de contato).
  \item Projeto das carcaças dos 3 efetuadores (garra de campo, garra de contato, funil/guia de captura do plugue NBR~14136) — a base de fixação no braço já existe, falta a peça específica de cada um.
  \item Definição empírica dos timeouts do failsafe (janela curta de reconexão vs.\ janela longa em estado engajado).
  \item Definição do protocolo exato de mensagens LoRa (formato de pacote, taxa de amostragem da telemetria).
  \item Projeto detalhado do aplicativo desktop (stack tecnológica, banco de dados local, layout do dashboard).
\end{itemize}

% =====================================================
% REGISTRO DE APROVAÇÃO
% =====================================================
\section*{Registro de aprovação}
\addcontentsline{toc}{section}{Registro de aprovação}

\begin{longtable}{@{}p{4.2cm}p{4.2cm}@{}}
\textbf{Elaborado por:} & \rule{4cm}{0.4pt} \\[1.4em]
\textbf{Data:} & \rule{4cm}{0.4pt} \\[1.4em]
\textbf{Orientador:} & \rule{4cm}{0.4pt} \\[1.4em]
\textbf{Assinatura:} & \rule{4cm}{0.4pt} \\
\end{longtable}

\vfill
\begin{center}
{\footnotesize\ttfamily\color{voltgray} SkyVolt \;\textbullet\; Documento de Requisitos, Arquitetura \& BOM \;\textbullet\; Revisão 1.3 \;\textbullet\; 14/08/2026}
\end{center}

\end{document}

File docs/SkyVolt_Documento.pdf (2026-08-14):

DOCUMENTO DE REQUISITOS, ARQUITETURA & BOM • REV. 1.3

plugue 3 pinos

garra de campo

garra de contato

NOME DE PROJETO

# SkyVolt

Drone medidor e fiscalizador de ambientes de alta e baixa energia

CURSO | Desenvolvimento de Aplicações Desktop
DATA | 14/08/2026
REVISÃO | 1.3

IMPRESSÃO 3D Fornecida pela faculdade — sem custo ao projeto

TETO DE ORÇAMENTO (EQUIPAMENTO) | R$ 2.000,00
GASTO MÉDIO ESTIMADO (BOM) | R$ 1.903,80
ELABORADO POR | ____________________________

vista superior esquemática — três efetuadores em posições distintas do drone

### Sumário

1 Visão geral do projeto | 2
2 Requisitos funcionais | 2
3 Requisitos não-funcionais e restrições | 2
4 Arquitetura do sistema | 3
5 Riscos e limitações conhecidas | 6
6 Levantamento de custos (BOM) | 6
7 Registro de decisões | 9
8 Pendências e trabalho futuro | 10
Registro de aprovação | 11

SkyVolt | Requisitos & Arquitetura

### 1 Visão geral do projeto

O SkyVolt é um hexacóptero de estrutura impressa em 3D (impressora fornecida pela faculdade, sem custo ao projeto) cuja função principal é medir tensão e corrente elétrica em pontos de um ambiente controlado, classificando automaticamente o tipo de circuito e reportando os dados a um aplicativo desktop de controle e monitoramento.

Princípio orientador de escopo: a medição é a função core do projeto; a plataforma voadora é secundária. Sempre que o orçamento ou o prazo exigirem corte de escopo, a prioridade recai sobre manter a função de medição íntegra, simplificando o drone antes de simplificar o sensoriamento.

Papel do aplicativo desktop (entregável central da disciplina): estação de controle e monitoramento, recebendo telemetria em tempo real via LoRa, exibindo tensão, corrente, temperatura e classificação num painel, mantendo histórico local de medições e emitindo alertas configuráveis.

Faixa elétrica do escopo: circuitos AC de até 220V (padrão residencial/tomada) e circuitos DC sempre ≤100V (restrição de projeto). Ambientes acima de 220V estão fora de escopo pelo risco de arco elétrico.

### 2 Requisitos funcionais

ID | Requisito
RF01 | Medir tensão AC/DC entre 5V e 220V, conforme o modo de contato dispo-
| nível.
RF02 | Medir corrente elétrica, por contato direto ou por indução (clamp sem
| contato).
RF03 | Estimar potência dissipada (Lei de Joule) a partir de leitura térmica.
RF04 | Transmitir telemetria de sensores (tensão, corrente, classificação AC/DC,
| modo utilizado) via LoRa até a estação base.
RF05 | Exibir os dados recebidos em tempo real no aplicativo desktop (dashboard).
RF06 | Registrar histórico de medições localmente (SD/flash) e sincronizar com o
| app quando o link permitir.
RF07 | Posicionar um entre três efetuadores — garra de campo, garra de contato
| ou plugue de 3 pinos — no ponto de medição, conforme o modo classificado.
RF08 | Emitir alerta no aplicativo quando valores excederem limites configuráveis.
RF09 | Transmitir vídeo de navegação (FPV) e comandos de voo via WiFi, com
| baixa latência.
RF10 | Classificar automaticamente o alvo (conector padrão / campo AC ≥100V /
| contato <100V ou DC) por reconhecimento sem contato, a uma distância
| de stand-off calibrada, sem informação prévia do operador.
RF11 | Executar rotina autônoma de segurança ao detectar qualquer falha, nave-
| gando até uma zona segura pré-estabelecida por marcador visual.

### 3 Requisitos não-funcionais e restrições

ID | Restrição
RNF01 | Teto de orçamento: R$ 2.000 para equipamento. Impressão 3D fornecida
| pela faculdade (acordo com o coordenador), sem custo ao projeto.
RNF02 | Isolamento galvânico entre o circuito medido (até 220V) e a eletrônica de
| controle; hardware do modo contato dimensionado para tolerar até 220V
| mesmo em caso de erro de classificação (defesa em profundidade).
RNF03 | Domínios de energia separados — propulsão, eletrônica/medição e supervi-
| sor de segurança — para evitar falha compartilhada.
RNF04 | Tolerância de posicionamento de ±1,5cm por eixo na abordagem manual,
| compensada por folga mecânica e funil de captura.
RNF05 | Autonomia mínima de voo de 8 a 12 minutos por missão.
RNF06 | Escopo elétrico fixo: DC sempre ≤100V; AC até 220V.
RNF07 | Redundância mínima de propulsão: tolerância a falha de 1 motor entre 6
| (hexacóptero).

### 4 Arquitetura do sistema

### 4.1 Estrutura e propulsão decidido

Estrutura impressa em impressora 3D fornecida pela faculdade (acordo com o coordenador, sem custo ao orçamento). Configuração hexacóptero (6 motores), escolhida como meio-termo entre custo e redundância mecânica: tolera a perda de 1 motor sem queda imediata, ao contrário de um quadricóptero, e custa/pesa menos que o octocóptero originalmente cogitado.

Motores brushless RS1606 3300KV (hélice 3", ESC brushless dedicado por motor) — decisão revisada na Rev. 1.2 a partir do fechamento da verificação de empuxo abaixo. A escolha original por motor de escova (Rev. 1.1) foi descartada: motor de escova compatível com o porte do frame não sustenta o peso estimado da aeronave. Motor brushless exige comutação eletrônica trifásica — um driver ponte-H simples (ex. L293D), adequado para motor de escova, não serve para acionar motor brushless; por isso cada motor tem um ESC dedicado no BOM (Seção 6.1).

Verificação de empuxo (thrust-to-weight) — fechada: peso bruto máximo estimado (cenário pessimista, todos os componentes) ≈1.110g — atualizado na Rev. 1.3 com o peso real da estrutura, obtido do CAD paramétrico (FreeCAD) em vez de estimativa de densidade: 264g para hub + 6 braços + bandeja de eletrônica (100% infill PETG). Motor RS1606 3300KV entrega até 875g de empuxo por motor com hélice de 4"(dado de fabricante, 23,7A/398W a 4S) — TWR≈4,7. Com hélice de 3"(empuxo reduzido, estimado por teoria de disco atuador na ausência de bancada publicada para esse par), TWR estimado ≈2,7–3,5, ainda acima do mínimo seguro de 1,5–2,0. A hélice de 3"foi escolhida no lugar da de 4"para também trazer a autonomia para dentro da janela de RNF05 sem alterar a bateria — ver Seção 4.4.

Estrutura modular (Rev. 1.3): o chassi foi redesenhado em 3 peças impressas separadamente — hub (129,6×121,2mm), braço (154×26mm, imprimir ×6) e bandeja de eletrônica (150×80mm) — todas dentro da mesa de impressão de 220×220mm do equipamento disponível (o frame original de peça única, 330×290mm, não cabia). Braço e hub se unem por encaixe lingueta/rasgo (tenon/mortise) reforçado com 2 parafusos M3 por junta (12 no total), mais resistente à flexão do que um encaixe topo-a-topo só parafusado. Pad do motor dimensionado para o RS1606 3300KV: padrão de furação quadrado 12×12mm, 4×M2 — padrão típico da classe 1606, não confirmado contra o datasheet oficial do fabricante (ver Seção 8).

### 4.2 Sistema de medição — função principal decidido

Três efetuadores especializados, cada um resolvendo um modo de medição diferente:

- Garra de campo (servo, retrátil) — medição sem contato, para AC ≥100V.
- Garra de contato (servo) — contato direto, para <100V ou DC.
- Plugue de 3 pinos (padrão NBR 14136), montado na lateral do drone, com funil/guia de captura impresso e ponta modular para adaptadores de outros tipos de tomada.

A escolha do efetuador segue uma triagem em três etapas: aproximação até uma distância de stand-off calibrada, reconhecimento sem contato (sensor de campo EMF + câmera térmica) e classificação — tudo decidido pelo próprio sistema, sem informação prévia do operador sobre o circuito, conforme resumido na tabela a seguir.

Fixação física (Rev. 1.3): os 6 braços do frame já saem impressos com base de fixação para servo SG90 (furação M2, espaçamento 32,5mm, padrão de mercado) — os 3 braços efetuadores usam essa base para a garra/plugue; os outros 3 ficam com a base livre, sem custo extra relevante de peso ou impressão. Carcaça específica de cada efetuador (garra de campo, garra de contato, funil do plugue NBR 14136) ainda não foi desenhada — ver Seção 8.

Árvore de triagem do sistema de medição

Condição | Modo escolhido | Precisão obtida
Conector padrão visível | Modo A — plugue 3 pinos | Tensão e corrente exatas, se- guro em qualquer tensão do escopo
Sinal AC no campo, ≥100V Modo B — campo (clamp) | Corrente exata; tensão em
| | faixa (limitação física)
Sinal AC no campo, <100V Modo B — contato | Tensão e corrente exatas, iso-
| | lado até 220V
Sem sinal AC (DC, ≤100V garantido) | Modo B — contato | Tensão e corrente exatas

### 4.3 Comunicação e redundância decidido

Dois rádios com papéis distintos, mapeados a dois microcontroladores independentes:

- WiFi (ESP32 #1): vídeo de navegação (FPV) + comandos de voo — baixa latência.
- LoRa (ESP32 #2): telemetria de sensores — pacotes pequenos, atua também como supervisor de segurança.

Os dois ESP32 trocam um heartbeat por fio (independente de rádio). O ESP32 #2 tem câmera própria dedicada e fonte de energia independente — nenhuma dependência compartilhada com o ESP32 #1 que pudesse derrubar os dois juntos.

Máquina de failsafe: qualquer problema detectado (perda de link, bateria crítica, falha de sensor/IMU, efetuador travado) aciona a mesma rotina — se engajado com o alvo, desengate controlado e lento primeiro; em seguida, navegação autônoma via marcador visual até a zona segura pré-estabelecida, pouso com motores desarmados e efetuador inerte.

### 4.4 Energia decidido

Domínio | Química/fonte | Proteção | Observação
Propulsão | Li-ion | alta | descarga
(18650/21700)

BMS obrigatório Mais seguro que LiPo em queda perto de circuito energizado
Eletrônica/medição Domínio próprio, separado da propulsão

Isolamento do sag
de tensão

Evita brownout do ESP32 durante o contato
Supervisor
(ESP32 #2)

Fonte independente dedicada

— | Sobrevive a falha da bateria de
eletrônica

Autonomia alvo por missão: 8 a 12 minutos (decolagem → aproximação → medição → retorno → pouso).

Estimativa de autonomia (atualizada na Rev. 1.3 com o peso real da estrutura): motor RS1606 3300KV + hélice 3", bateria de propulsão mantida sem alteração (4× células 21700 alta descarga, 4,2Ah, 4S1P, ≈48,4Wh utilizáveis). Potência em hover estimada em ≈277W (era 248W na Rev. 1.2, antes do peso real do CAD) → autonomia ≈10,5 minutos, ainda dentro da janela de RNF05 mas com menos folga que antes. Estimativa apoiada em extrapolação de curva de eficiência de motor similar (sem bancada real do par motor+hélice escolhido) — ver pendência na Seção 8.

### 4.5 Iluminação decidido

LED difuso, para a câmera normal de navegação (FPV) em ambientes escuros — difuso em vez de focado para evitar reflexo em contatos metálicos. Controle manual, ligado/desligado pelo piloto.

### 4.6 PCBs decidido

Placas perfuradas de 1 camada, soldadas à mão, divididas por domínio funcional: potência/propulsão, ESP32 #1, ESP32 #2, sensores de medição (duas metades fisicamente separadas — lado perigoso e lado seguro, isolados por optoacoplador certificado) e adaptador do Modo A. Sem plano de terra, a separação física da placa de potência e o aterramento em estrela ganham ainda mais importância para reduzir ruído de chaveamento contaminando a leitura.

Fixação física (Rev. 1.3): bandeja impressa dedicada (150×80mm), aparafusada nos 4 furos de coluna do hub por espaçadores/standoffs — carrega os 2 ESP32-S3 em trilhos dimensionados para o footprint oficial do DevKitC-1 (70×28mm) e os 2 módulos LoRa em baia genérica com abraçadeira (footprint do módulo real ainda não confirmado — ver Seção 8).

### 5 Riscos e limitações conhecidas

# | Risco / limitação | Status

1 | Cenário máximo (R$ 2.674,70) ainda ultrapassa o teto de R$ 2.000 caso cotações finais batam no topo da faixa. | limitação
2 | Redundância de motor reduzida (hexacóptero vs. octocóp- tero original). | troca aceita
3 | Empuxo e autonomia do par motor RS1606 3300KV + hélice 3"baseados em extrapolação de curva de eficiência, não em bancada real do par escolhido (TWR≈2,7–3,5; autonomia ≈10,5min). | mitigado parcial
4 | Tensão exata não garantida em pontos sem conector acima
| de 100V. | limitação
5 | Interferência eletromagnética do próprio circuito medido
| no link WiFi. | limitação
6 | Contato físico em até 220V exige isolamento rigoroso. | decidido
7 | Bateria danificada em queda perto de circuito energizado
| — risco composto. | decidido
8 | Falha compartilhada de bateria de eletrônica derrubando
| os dois ESP32. | decidido
9 | Falha compartilhada de câmera entre ESP32 #1 e #2. | decidido
10 | Ausência de plano de terra (PCB 1 camada) aumenta
| suscetibilidade a ruído. | mitigado parcial
11 | Precisão do encaixe do plugue incompatível com tolerância
| de pilotagem manual. | decidido
12 | Drone preso ao alvo indefinidamente se o link cair durante
| contato. | decidido

### 6 Levantamento de custos (BOM)

Os valores abaixo combinam cotações diretas de mercado brasileiro (agosto/2026, marcadas com †
) e estimativas de engenharia para itens sem padronização de preço (componentes equivalentes, faixa de mercado observada). Colunas Mín., Méd. e Máx. representam o cenário mais barato, o cenário médio esperado e o cenário mais caro plausível por item.

### 6.1 Estrutura e propulsão

Item | Qtd | Mín. un. | Méd. un. | Máx. un. | Total (méd.)
Motor brushless RS1606 3300KV 6 | R$ 35,00 | R$ 50,00 | R$ 70,00 | R$ 300,00
ESC brushless 30A (dedicado por motor) | 6 | R$ 18,00 | R$ 25,00 | R$ 35,00 | R$ 150,00
Kit hélices 3"(jogo + reservas) | 1 | R$ 20,00 | R$ 35,00 | R$ 50,00 | R$ 35,00
Filamento PLA/PETG (chassi) | 1 | R$ 30,00 | R$ 45,00 | R$ 60,00 | R$ 45,00
Subtotal — Mín. R$ 368,00 | Méd. R$ 530,00 | Máx. R$ 740,00

### 6.2 Controle e comunicação

Item | Qtd | Mín. un. | Méd. un. | Máx. un. | Total (méd.)
ESP32-S3 (módulo dev)† | 2 | R$ 27,34 | R$ 45,00 | R$ 74,80 | R$ 90,00
Módulo LoRa SX1276/RFM95† | 2 | R$ 70,00 | R$ 79,90 | R$ 90,00 | R$ 159,80
Subtotal — Mín. R$ 194,68 | Méd. R$ 249,80 | Máx. R$ 329,60

### 6.3 Câmeras

Item | Qtd | Mín. un. | Méd. un. | Máx. un. | Total (méd.)
Câmera térmica MLX90640† | 1 | R$ 180,00 | R$ 260,00 | R$ 400,00 | R$ 260,00
Câmera FPV + VTX (navega- ção) | 1 | R$ 90,00 | R$ 150,00 | R$ 250,00 | R$ 150,00
Câmera dedicada ESP32 #2 (OV2640)† | 1 | R$ 25,00 | R$ 40,00 | R$ 55,00 | R$ 40,00
Subtotal — Mín. R$ 295,00 | Méd. R$ 450,00 | Máx. R$ 705,00

### 6.4 Sensores de medição

Item | Qtd | Mín. un. | Méd. un. | Máx. un. | Total (méd.)
Sensor de campo EMF (não- contato) | 1 | R$ 30,00 | R$ 50,00 | R$ 70,00 | R$ 50,00
Clamp de corrente SCT-013† | 1 | R$ 47,50 | R$ 55,00 | R$ 63,10 | R$ 55,00
Sensor Hall/shunt de contato (ACS712) | 1 | R$ 15,00 | R$ 20,00 | R$ 28,00 | R$ 20,00
Optoacoplador PC817 (módulo)† 2 | R$ 7,00 | R$ 8,00 | R$ 12,00 | R$ 16,00
Fusível/PTC + proteção | 1 | R$ 5,00 | R$ 10,00 | R$ 15,00 | R$ 10,00
Subtotal — Mín. R$ 111,50 | Méd. R$ 151,00 | Máx. R$ 200,10

### 6.5 Efetuadores

Item | Qtd | Mín. un. | Méd. un. | Máx. un. | Total (méd.)
Micro servo (SG90 ou equiv.)† | 3 | R$ 16,90 | R$ 19,00 | R$ 25,00 | R$ 57,00
Plugue NBR 14136 + adaptado- res | 1 | R$ 15,00 | R$ 25,00 | R$ 35,00 | R$ 25,00
Funil de captura + filamento ex- tra | 1 | R$ 10,00 | R$ 15,00 | R$ 20,00 | R$ 15,00

Item | Qtd | Mín. un. | Méd. un. | Máx. un. | Total (méd.)
Hardware das garras (dobradiças, fixação) | 1 | R$ 20,00 | R$ 35,00 | R$ 50,00 | R$ 35,00
Subtotal — Mín. R$ 95,70 | Méd. R$ 132,00 | Máx. R$ 180,00

### 6.6 Energia

Item | Qtd | Mín. un. | Méd. un. | Máx. un. | Total (méd.)
Célula Li-ion 18650/21700 alta descarga† | 4 | R$ 25,00 | R$ 35,00 | R$ 45,00 | R$ 140,00
BMS (pack propulsão) | 1 | R$ 25,00 | R$ 40,00 | R$ 60,00 | R$ 40,00
Bateria eletrônica (domínio me- dição) | 1 | R$ 20,00 | R$ 30,00 | R$ 40,00 | R$ 30,00
Bateria backup ESP32 #2 | 1 | R$ 10,00 | R$ 17,00 | R$ 25,00 | R$ 17,00
Subtotal — Mín. R$ 155,00 | Méd. R$ 227,00 | Máx. R$ 305,00

### 6.7 Iluminação, PCB e montagem

Item | Qtd | Mín. un. | Méd. un. | Máx. un. | Total (méd.)
LED difuso + driver/resistor | 1 | R$ 10,00 | R$ 17,00 | R$ 25,00 | R$ 17,00
Placa perfurada (protoboard) | 6 | R$ 8,00 | R$ 12,00 | R$ 15,00 | R$ 72,00
Fios, conectores, solda, hardware geral | 1 | R$ 50,00 | R$ 75,00 | R$ 100,00 | R$ 75,00
Subtotal — Mín. R$ 108,00 | Méd. R$ 164,00 | Máx. R$ 215,00

### 6.8 Resumo geral e comparação com o orçamento

Categoria | Mín. | Méd. | Máx.
Estrutura e propulsão | R$ 368,00 | R$ 530,00 | R$ 740,00
Controle e comunicação | R$ 194,68 | R$ 249,80 | R$ 329,60
Câmeras | R$ 295,00 | R$ 450,00 | R$ 705,00
Sensores de medição | R$ 111,50 | R$ 151,00 | R$ 200,10
Efetuadores | R$ 95,70 | R$ 132,00 | R$ 180,00
Energia | R$ 155,00 | R$ 227,00 | R$ 305,00
Iluminação, PCB e montagem | R$ 108,00 | R$ 164,00 | R$ 215,00
TOTAL DO PROJETO | R$ 1.327,88 | R$ 1.903,80 | R$ 2.674,70

Orçamento cabe no cenário provável, com folga reduzida: com o teto revisado para R$ 2.000,00 e a impressão 3D fora do orçamento (fornecida pela faculdade), tanto o cenário mínimo (R$ 1.327,88) quanto o médio (R$ 1.903,80) ficam dentro do teto, com folga de R$ 672,12 e R$ 96,20 respectivamente. A troca para motor brushless (Rev. 1.2) reduziu a folga do cenário médio de R$ 312,20 para R$ 96,20 — margem bem mais apertada que antes.

Risco remanescente — cenário máximo: o cenário mais caro (R$ 2.674,70) ainda ultrapassa o teto de R$ 2.000,00 em R$ 674,70 (era R$ 374,70 antes da troca de motor). O conjunto motor+ESC brushless (R$ 312 de oscilação combinada) passou a rivalizar com a câmera térmica MLX90640 (R$ 180 a R$ 400, variação de R$ 220) como maior fator de risco orçamentário, seguidos pela câmera FPV+VTX e pelo pack de energia. Cotação formal do motor/ESC antes da compra é recomendada dado o novo impacto no teto.

### 7 Registro de decisões

Decisão | Alternativa | conside-
rada

Justificativa

Hexacóptero | Quadricóptero / octocóp-
tero

Meio-termo entre custo e redundância de motor
Motor | brushless
RS1606 | 3300KV | +
hélice 3"

Motor de escova (decisão
original, Rev. 1.1); motor brushless 2205/2207

Verificação de TWR (peso pessimista ≈991g) mostrou que motor de escova não sustenta o peso; motor 2205/2207 sustenta com folga mas puxa corrente (>20A/motor) incompatível com a bateria do BOM; RS1606+hélice 3"fecha TWR
seguro (≈3–4×) e autonomia ≈11,7min (RNF05)
Manter a bateria de propulsão original (4× 21700
alta descarga, 4,2Ah)

Redimensionar a bateria
para a nova autonomia

Evita retrabalho na célula já escolhida; hélice 3"(menos eficiente que 4") absorve o excesso de autonomia e traz o tempo de voo para dentro de 8–12min sem mexer na bateria
Frame em 3 peças modulares (hub + braço ×6 +
bandeja de eletrônica), encaixe lingueta/rasgo + parafuso M3
Frame em peça única | Peça única (330×290mm) não
cabe na mesa de impressão de 220×220mm disponível; encaixe lingueta/rasgo resiste a flexão melhor que topo-a-topo só parafusado

Decisão | Alternativa | conside-
rada

Justificativa

Bandeja de eletrônica separada, aparafusada no hub
por standoffs

ESP32/LoRa direto no
hub

Hub não tem área livre para
2×ESP32-S3 | (70×28mm) | +
2×LoRa sem competir com o
favo de mel e os braços; bandeja em segundo andar resolve o conflito de espaço
Base de servo (SG90) presente nos 6 braços, não só nos 3 efetuadores

Base só nos 3 braços efetuadores

Mantém a peça do braço
única/intercambiável para
impressão; custo de peso extra nos 3 braços sem efetuador é desprezível
Abordagem manual via
FPV

Navegação autônoma completa

Reduz escopo de software; drone é secundário à medição
Três efetuadores especializados

Um único efetuador genérico

Cada modo de medição tem exigência física distinta
Triagem autônoma às cegas
Operador | pré-define | o
modo

Exigência do projeto: sistema deve classificar sozinho
Li-ion 18650/21700 na propulsão
LiPo tradicional | Menor risco de incêndio em
queda perto de circuito energizado
Dois domínios de bateria | Bateria única com BEC | Evita brownout do ESP32 du-
rante o contato de medição Dois ESP32 com papéis
distintos

Um único ESP32 fazendo
tudo

Redundância de rádio e supervisor de segurança independente Navegação de emergência
por marcador visual
Dead-reckoning puro | Mais robusto contra deriva; pro-
blema de visão contido a um alvo fixo
Placa de medição em duas
metades separadas

Duas zonas na mesma
placa

Isolamento físico real, independente da solda manual
PCB em protoboard (1 camada)

Fabricação profissional sob encomenda

Economia de orçamento e prazo

### 8 Pendências e trabalho futuro

- Validação em bancada real do motor RS1606 3300KV com hélice de 3"(empuxo e corrente em throttle parcial) — a autonomia estimada (≈10,5min) usa extrapolação da curva de eficiência de outro motor, não dado medido do par escolhido.
- Confirmação do padrão de furação real do RS1606 (assumido 12×12mm, 4×M2 — padrão típico da classe 1606, não confirmado contra datasheet do fabricante) antes de imprimir o braço em lote.
- Confirmação do footprint real do módulo LoRa (SX1276/RFM95) para apertar o encaixe da bandeja de eletrônica — hoje é uma baia genérica com abraçadeira por falta de dado de fixação confirmado.
- Cotação formal do motor brushless RS1606 3300KV e do ESC dedicado — juntos, tornaram-se o maior fator de oscilação do orçamento (R$ 312 de variação combinada), reduzindo a folga do cenário médio para R$ 96,20.
- Peso da estrutura impressa (hub + 6 braços + bandeja) já confirmado por CAD real: 264g. Falta confirmar o peso real dos demais componentes (motor, ESC, bateria, eletrônica, sensores) contra a estimativa pessimista usada na verificação de empuxo (≈1.110g no total).
- Fechamento do BOM com cotações formais (não estimativas) para os itens sem preço pesquisado.
- Cotação formal da câmera térmica MLX90640 antes das demais compras — é o item de maior risco de estourar o teto de R$ 2.000,00 no cenário máximo.
- Escolha de modelos específicos de sensor (clamp de corrente, sensor de campo EMF, sensor Hall/shunt de contato).
- Projeto das carcaças dos 3 efetuadores (garra de campo, garra de contato, funil/guia de captura do plugue NBR 14136) — a base de fixação no braço já existe, falta a peça específica de cada um.
- Definição empírica dos timeouts do failsafe (janela curta de reconexão vs. janela longa em estado engajado).
- Definição do protocolo exato de mensagens LoRa (formato de pacote, taxa de amostragem da telemetria).
- Projeto detalhado do aplicativo desktop (stack tecnológica, banco de dados local, layout do dashboard).

### Registro de aprovação

Elaborado por:

Data:

Orientador:

Assinatura:

SkyVolt • Documento de Requisitos, Arquitetura & BOM • Revisão 1.3 • 14/08/2026

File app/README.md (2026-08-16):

#  SKYVOLT - Estação de Controle e Monitoramento Desktop

O **SKYVOLT** é um aplicativo desktop desenvolvido como entregável central da disciplina. Ele funciona como uma estação de controle e monitoramento, projetada para receber telemetria em tempo real via comunicação de rádio **LoRa** e apresentar dados críticos em um painel interativo.

---

##  Descrição do Projeto

O sistema é responsável por capturar, processar e apresentar as seguintes grandezas elétricas e físicas:
*   **Tensão** (V)
*   **Corrente** (A)
*   **Temperatura** (°C)
*   **Classificação do estado da rede** (Normal, Sobrecarga, Subtensão, etc.)
---

##  Requisitos e Funcionalidades

O escopo completo do projeto está distribuído nos seguintes documentos internos do repositório:

*   **Requisitos Funcionais Detalhados:** Encontre a lista completa (detalhando o Dashboard, controle do disjuntor, corte de emergência, definição de setpoints e tabela de histórico) em [requisitos_app_desktop.md](file:///docs/requisitos_app_desktop.md).
*   **Checklist da Primeira Entrega (Simulação):** O progresso e os itens avaliativos obrigatórios estão listados em [ideia_A1_1.md](file:///ideias/ideia_A1_1.md).
*   **Pendências e Definições Futuras:** A stack complementar (como banco de dados local definitivo e layout final do dashboard) ainda está em fase de definição — consulte a **Seção 8 (Pendências)** do documento conceitual [SkyVolt_Documento.pdf](file:///docs/SkyVolt_Documento.pdf).

---

## (Desktop App)

A interface gráfica foi estruturada com:

*   **Python **: Linguagem de desenvolvimento principal.
*   **PyQt5**: Toolkit para desenvolvimento da interface gráfica nativa.
*   **PyQtGraph**: Biblioteca de plotagem de alto desempenho integrada para renderização ágil de gráficos de telemetria em tempo real.

---

##  Como Rodar a Aplicação

### 1.
Certifique-se de que está no diretório raiz do projeto e execute:
```bash
pip install -r requirements.txt
python -m app.main

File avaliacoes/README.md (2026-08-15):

# Avaliações

Registro das devolutivas oficiais do professor para cada entrega da disciplina 34943 — Desenvolvimento de Aplicações Computacionais: nota, feedback e pontos a corrigir.

Diferença em relação a `ideias/`: lá o time documenta o que **planeja** fazer (roadmap, checklist por critério); aqui documenta-se o que o professor **efetivamente avaliou**, depois da entrega. Servem para o time acompanhar a evolução do projeto.

## Índice

| Entrega | Peso | Data | Status |
|---|---|---|---|
| [A1/1] | 2,0 | 17/08/2026 | aguardando |
| [A1/2] | TBD | TBD | aguardando |
| [A1/3] | TBD | TBD | aguardando |
| [A1/4] | TBD | TBD | aguardando |
| [A1/5] | TBD | TBD | aguardando |
| [Apresentação final] | TBD | 01–02/12/2026 | — | aguardando |

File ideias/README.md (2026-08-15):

Este documento reunirá propostas e conceitos relacionados ao projeto durante toda a sua fase de execução.

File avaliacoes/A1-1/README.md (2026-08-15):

Aqui se encontra o trabalho de A1-1(17/08/2026).

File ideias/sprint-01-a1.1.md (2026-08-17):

# Sprint 1 — Divisão de Tarefas (A1/1)

**Entrega:** 17/08/2026 · **Documento criado:** 16/08/2026 · **Referência:** [`ideia_A1_1.md`](ideia_A1_1.md) (checklist oficial da entrega) e [`roadmap.md`](roadmap.md) (Sprint 1)

Este documento detalha **quem faz o quê** no que falta para a A1/1, com base no padrão de trabalho que o time já vinha seguindo (cada pessoa concentrada numa camada da arquitetura MVC).

---

## 1. Estado atual (levantamento de 16/08/2026)

O app já **roda sem erros** (`python -m app.main`) e a estrutura MVC está correta (`ui/` sem lógica, `controllers/` com os signals/slots, `models/` com os dados). O que falta para bater o checklist da entrega:

| Item do checklist | Situação | Bloqueia |
|---|---|---|
| Gráfico de tendência já populado ao abrir (não pode abrir vazio) | ❌ `graficoConsumo` só recebe eixo/grid, nunca dado (`main_controller.py:67`) | — (Matheus resolve sozinho) |
| Indicador de Temperatura | ❌ não existe na UI nem no model | Robertson (UI) + Vitória (model) |
| Classificação automática do circuito (AC/DC, faixa de tensão) | ❌ não existe na UI nem no model | Robertson (UI) + Vitória (model) |
| Painel de Recepção (simulado): combo porta COM, baud rate 9600/115200, timeout, Conectar/Desconectar | ❌ não existe | Robertson (UI) |
| Corte de emergência com `QMessageBox.question` de confirmação | ❌ `alternar_disjuntor()` age direto, sem confirmar | — (Matheus resolve sozinho) |
| Formatação PT-BR nos valores (vírgula decimal) | ⚠️ `formatacao.py` já existe mas não é usado — labels mostram `str(valor)` cru | — (Matheus resolve sozinho) |
| `dateInicio` do `ConfigDialog` não é preenchido a partir da configuração atual | ⚠️ TODO em `config_controller.py:32` | — (Matheus resolve sozinho) |

---

## 2. Robertson Moura ([@Sophthe141](https://github.com/Sophthe141)) — UI / Qt Designer

Área de sempre: `app/ui/*.ui` + `.qss`. **Não mexer em lógica** (nenhum `.py` de `controllers/` ou `models/`) — só desenhar os widgets e deixar os `objectName` certos para o controller.

### Tarefas

1. **Indicador de Temperatura** — no `main_window.ui`, dentro do mesmo `verticalLayout` onde estão `lblTensaoValor`/`lblCorrenteValor`/`lblPotenciaValor`:
   - Um `QLabel` de legenda (padrão dos `txtCorrenteValor_x` que já existem, ex. "TEMPERATURA (°C):").
   - Um `QLabel` de valor com `objectName = lblTemperaturaValor` (mesmo padrão de `lblTensaoValor`).

2. **Classificação automática do circuito** — mesmo bloco:
   - `QLabel` de legenda ("CLASSIFICAÇÃO:").
   - `QLabel` de valor com `objectName = lblClassificacaoValor`.

3. **Painel de Recepção (simulado)** — novo `QGroupBox` (ex. "Recepção LoRa"), pode ficar abaixo dos botões `btnAlternarDisjuntor`/`btnConfiguracoes` ou num layout novo à direita:
   - `QComboBox objectName = cmbPortaCOM` (itens de exemplo: `COM1`, `COM2`, `COM3` — vai ser populado por código depois, mas deixe 2-3 itens fixos por enquanto).
   - `QComboBox objectName = cmbBaudRate` com itens `9600` e `115200`.
   - `QSpinBox objectName = spnTimeout` (ex. 1–30, padrão 5).
   - `QPushButton objectName = btnConectar` (texto "Conectar").
   - `QPushButton objectName = btnDesconectar` (texto "Desconectar", pode iniciar desabilitado).
   - `QLabel objectName = lblStatusConexao` (texto inicial "Desconectado").

4. **Regenerar o `_ui.py`** depois de editar o `.ui` no Qt Designer:
   ```bash
   pyuic5 app/ui/main_window.ui -o app/ui/main_window_ui.py
   ```
   Não editar `main_window_ui.py` na mão — ele é gerado (tem o aviso "WARNING: Any manual changes... will be lost").

5. Commitar **com seu próprio usuário GitHub** (`@Sophthe141`), em pelo menos 2 commits separados ao longo do dia (não tudo de uma vez) — é critério de nota do professor.

### Critério de pronto
Abrir `python -m app.main` e ver na tela: label de Temperatura, label de Classificação, e o grupo de Recepção com os widgets acima — mesmo que ainda sem lógica por trás (é o próximo passo, do Matheus).

---

## 3. Vitória ([@Viihvendausen](https://github.com/Viihvendausen)) — Models / Simulação de dados

Área de sempre: `app/models/telemetria.py`, `dados_simulados.py`, `evento.py`, `formatacao.py`. **Não mexer em `controllers/` nem em `ui/`.**

### Tarefas

1. **Estender `LeituraTelemetria`** em `telemetria.py` com os dois campos novos:
   ```python
   @dataclass
   class LeituraTelemetria:
       timestamp: datetime
       tensao: float
       corrente: float
       disjuntor_fechado: bool
       temperatura: float      # novo
       classificacao: str      # novo — ex. "AC 220V", "DC 12V"
   ```

2. **Simular temperatura** em `ler_telemetria()` — algo simples e plausível, ex. `random.gauss(35.0, 3.0)` (°C, ambiente de quadro elétrico), arredondado em 1 casa.

3. **Função de classificação automática** — nova função em `telemetria.py`:
   ```python
   def classificar_circuito(leitura: LeituraTelemetria) -> str:
       """Classifica o circuito como AC/DC e a faixa de tensão, a partir da leitura simulada."""
   ```
   Para a simulação (ainda sem hardware real — isso só entra na Unidade 4), pode fixar um critério simples e documentado no docstring, ex.: acima de 100V = "AC 220V", abaixo = "DC 12V" — o importante é que a função exista e retorne algo coerente com `leitura.tensao`, já que o professor só pede que o indicador **exista e funcione com dado simulado**.

4. **Atualizar `dados_simulados.py`** (`gerar_curva_consumo`) para também gerar uma lista de temperaturas (mesmo padrão de `horas`/`tensoes`/`correntes`), já que o gráfico populado (tarefa do Matheus) pode querer plotar temperatura também no futuro. Não é obrigatório para o gráfico inicial (que é de tensão), mas deixa pronto.

5. **Formatação** — conferir se `formatacao.py` precisa de um `formatar_temperatura(valor: float) -> str` (padrão `"xx,x °C"`, mesmo estilo de `formatar_tensao`). Adicionar se fizer sentido.

6. Commitar **com seu próprio usuário GitHub** (`@Viihvendausen`), em mais de um commit ao longo do dia.

### Critério de pronto
`ler_telemetria()` retorna `temperatura` e `classificacao` preenchidos; `classificar_circuito()` existe e tem pelo menos um teste manual (`python -c "..."`) mostrando que funciona para tensão alta e baixa.

---

## 4. Matheus ([@aCoruja](https://github.com/aCoruja)) — Controllers / Integração

Área de sempre: `app/controllers/*.py`. Consome o que Robertson (UI) e Vitória (models) entregarem. As tarefas abaixo **1 a 4 não dependem de ninguém** e podem começar imediatamente; **5 e 6 dependem** dos outros dois.

### Tarefas independentes (fazer primeiro)

1. **Ligar o gráfico** — em `main_controller.py`, importar `gerar_curva_consumo` de `app.models.dados_simulados` e, em `carregar_grafico()`, plotar o histórico simulado assim que a janela abre (`self.graficoConsumo.plot(horas, tensoes, ...)`), para não abrir vazio.

2. **Usar `formatacao.py`** em `atualizar_telemetria()` no lugar de `str(leitura.tensao)` etc. — trocar pelos `formatar_tensao`/`formatar_corrente`/`formatar_potencia` já prontos.

3. **Confirmação no corte de emergência** — em `alternar_disjuntor()`, antes de abrir o disjuntor, chamar `QMessageBox.question(...)` e só agir se o usuário confirmar (só precisa confirmar ao **abrir**, não ao fechar).

4. **Corrigir `dateInicio`** — em `config_controller.py`, `preencher_dialog()`, preencher `self.dateInicio` a partir de `configuracao.data_inicio` (`QDate` a partir de `date` do Python — `QDate(ano, mes, dia)` ou `QDate.fromString`).

### Tarefas dependentes (fazer depois que Robertson/Vitória commitarem)

5. **Ligar Temperatura e Classificação** — em `atualizar_telemetria()`, atualizar `self.lblTemperaturaValor` e `self.lblClassificacaoValor` com os novos campos de `LeituraTelemetria` (depende dos objectName do Robertson e dos campos da Vitória).

6. **Ligar o painel de Recepção** — conectar `btnConectar`/`btnDesconectar` para só alternar `lblStatusConexao` visualmente (o requisito da A1/1 é só simulado — não precisa abrir porta serial de verdade ainda, isso é Unidade 4).

### Critério de pronto
Checklist completo de [`ideia_A1_1.md`](ideia_A1_1.md) batendo, app rodando sem erro, gráfico populado ao abrir.

---

## 5. Ordem de dependências

```
Robertson (UI: labels + painel LoRa)  ─┐
                                        ├──► Matheus (tarefas 5-6: ligar na lógica)
Vitória (models: temperatura/classif.) ─┘

Matheus (tarefas 1-4): sem dependência, pode rodar em paralelo com os dois acima
```

Robertson e Vitória podem trabalhar ao mesmo tempo — não mexem nos mesmos arquivos. Matheus faz 1-4 enquanto espera, depois puxa os commits dos outros dois (`git pull`) e faz 5-6 por último.

---

## 6. Regras do professor (lembrete — valem para todos)

- **Cada integrante precisa aparecer no histórico de commits com o próprio usuário GitHub** — quem não commitar tira ZERO na entrega, independente do time ter entregue certo.
- **Não concentrar tudo nos commits de um único dia** — espalhar ao longo da sprint, mesmo que a maior parte do trabalho tenha sido feita perto do prazo.
- Mensagens de commit claras e coerentes com o que foi feito (ex. `feat(ui): adiciona indicadores de temperatura e classificação`, não `update`).

---

## 7. Checklist final antes de entregar

- [ ] Gráfico abre já populado (não vazio)
- [ ] Temperatura e Classificação AC/DC visíveis e atualizando
- [ ] Painel de Recepção (COM/baud/timeout/Conectar/Desconectar) presente, mesmo que só visual
- [ ] Corte de emergência pede confirmação (`QMessageBox.question`)
- [ ] Valores exibidos em formato PT-BR (vírgula decimal)
- [ ] `README.md` da raiz com os 3 integrantes e usuários GitHub corretos
- [ ] Commits dos 3 integrantes presentes, espalhados ao longo da sprint

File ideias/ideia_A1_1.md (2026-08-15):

# Objetivos do Trabalho - App Desktop SkyVolt (Entrega 17/08/2026)

> ⚠️ **AVISO IMPORTANTE:**
> Todo sprint descrito neste documento representa uma *ideia* e um planejamento de como poderá ser a entrega **A1-1**, e não significa que o resultado final será total e estritamente assim. O escopo pode sofrer adaptações. Para conferir o resultado final validado, consulte sempre o diretório `avaliações/`.

---

## 1. Arquitetura e Estrutura do Software
* **Implementar o Padrão MVC:** Organizar o projeto estritamente em pastas:
  * `ui/`: Apenas arquivos de interface (telas do Qt Designer e seus arquivos `.py` compilados). **Zero lógica de negócio.**
  * `controllers/`: Gerenciamento das janelas, *Signals* e *Slots*.
  * `models/`: Gerenciamento de estado e dados (histórico simulado, telemetria, valores de setpoints).
  * `main.py`: Arquivo de entrada exclusivo para inicializar a aplicação.

## 2. Interface Gráfica (UI) e Layout
* **Dashboard Responsivo:** Construir o painel principal utilizando *layouts* adequados (Grid/Box), garantindo hierarquia visual sem usar posições fixas ou sobrepostas.
* **Indicadores Obrigatórios (Professor):** Exibir com destaque a Tensão (V), Corrente (I) e Potência (P) usando `QLCDNumber` ou `QLabel`.
* **Indicadores Específicos do SkyVolt:** Mostrar a Temperatura e a Classificação Automática do Circuito (AC/DC e faixa de tensão).
* **Status do Disjuntor (Circuito Monitorado):** Adicionar indicador visual do disjuntor do circuito inspecionado pelo drone (Verde para "FECHADO/NORMAL" e Vermelho para "ABERTO/PROTEÇÃO ATIVADA").
* **Gráfico de Tendência Inicializado:** Integrar um gráfico (via PyQtGraph ou Matplotlib) que já inicie populado com um histórico simulado de dados ao abrir o aplicativo (não pode abrir vazio).
* **Painel de Recepção (Simulado):** Criar a área de configuração da comunicação (futuro rádio LoRa) com `QComboBox` para porta COM, opções de *baud rate* (9600/115200), *timeout* e botões de Conectar/Desconectar. Nesta etapa, deve apenas alterar o status visualmente.

## 3. Funcionalidades e Interações (Lógica e *Widgets*)
* **Botão de Corte de Emergência:** Implementar a ação de corte exigindo uma janela de confirmação de segurança (`QMessageBox.question`) antes de prosseguir.
* **Configuração de Limites (Setpoints):** Criar uma janela modal (`QDialog`) para definir regras de limite de operação (mínimo de 2 regras, ex.: Tensão e Corrente). Utilizar `QSpinBox`, `QDoubleSpinBox` ou `QSlider`. Os valores devem ser devolvidos e aplicados na tela principal.
* **Tabela de Histórico de Eventos:** Implementar um `QTableWidget` contendo as colunas: Data/Hora, Tipo de Evento, Descrição e Valor Medido.

## 4. Lógica de Negócio (Eventos e Simulação)
* **Gatilho de Setpoint:** Criar a lógica para que, quando um dado simulado ultrapassar o limite configurado, o dashboard mude para estado de alerta (cores amarelo/vermelho) e uma nova linha seja registrada automaticamente na Tabela de Histórico.
* **Gatilho de Disjuntor:** Fazer com que a mudança simulada de estado do disjuntor dispare um aviso na tela (`QMessageBox.warning`) e adicione um novo registro na Tabela de Histórico.

## 5. Controle de Versão e Entregáveis (Regras da Equipe)
* **Commits Individuais:** Cada membro deve *commitar* o código usando seu próprio usuário do GitHub.
* **Distribuição de Trabalho:** Os *commits* devem ser distribuídos ao longo do final de semana de forma realista (não concentrar tudo no domingo). As mensagens de *commit* devem ser claras e coerentes com a funcionalidade entregue.
* **Documentação Final:** O arquivo `README.md` da raiz do repositório deve ser atualizado com os nomes de todos os integrantes antes do fechamento da entrega.

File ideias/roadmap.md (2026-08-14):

# Roadmap — 14/08/2026 a 02/12/2026

Semanal, alinhado ao calendário oficial da disciplina (34943 — Desenvolvimento de Aplicações Computacionais). Datas de A1/1 a A1/5 e das Unidades são as publicadas pelo professor; o **conteúdo específico de A1/2 a A1/5 ainda não foi divulgado** — as linhas marcadas `TBD` devem ser atualizadas assim que o enunciado de cada etapa sair.

| Sprint | Período | Marco do professor | Foco | Status |
|---|---|---|---|---|
| 1 | 14/08 – 17/08 | **A1/1** (Aula 04) | App desktop PyQt, arquitetura MVC, dashboard com dados simulados — ver `sprint-01-a1.1.md` | a fazer |
| 2 | 18/08 – 24/08 | — | Retro da A1/1 (nota, feedback do professor) + início Unidade 2 (Aula 05, 31/08) | a fazer |
| 3 | 25/08 – 31/08 | Aula 05 | Conteúdo de Unidade 2 em sala — TBD | a fazer |
| 4 | 01/09 – 07/09 | — | Preparação A1/2 — TBD (aguardando enunciado) | a fazer |
| 5 | 08/09 – 14/09 | **A1/2** (Aula 06) | Entrega A1/2 — TBD | a fazer |
| 6 | 15/09 – 21/09 | Aula 07 | Início Unidade 3 — TBD | a fazer |
| 7 | 22/09 – 28/09 | Aula 08 | Unidade 3 — TBD | a fazer |
| 8 | 29/09 – 05/10 | Aula 09 | Unidade 3 — TBD | a fazer |
| 9 | 06/10 – 12/10 | — | Preparação A1/3 — TBD | a fazer |
| 10 | 13/10 – 19/10 | **A1/3** (Aula 10) | Entrega A1/3 — TBD | a fazer |
| 11 | 20/10 – 26/10 | Aula 11 | **Início Unidade 4 — integração serial real com o hardware** (microcontrolador ↔ app desktop, conforme enunciado da A1/1) | a fazer |
| 12 | 27/10 – 02/11 | — | Integração serial: leitura de V/I real, acionamento de relé real | a fazer |
| 13 | 03/11 – 09/11 | Aula 12 | Unidade 4 — TBD | a fazer |
| 14 | 10/11 – 16/11 | **A1/4** (Aula 13) | Entrega A1/4 — provavelmente integração hardware fechada — TBD | a fazer |
| 15 | 17/11 – 23/11 | **A1/5** (Aula 14) | Entrega A1/5 — provavelmente polimento/testes — TBD | a fazer |
| 16 | 24/11 – 30/11 | Aula 15 | Última aula — ensaio geral, revisão de bugs, checklist de apresentação | a fazer |
| 17 | 01/12 – 02/12 | **Apresentação final** | Demo ao vivo, deploy/instalação testados numa máquina limpa | a fazer |

## Regras fixas do professor (valem em toda sprint, não só na entrega)

- **Nunca commitar tudo de uma vez no dia da entrega** — commits precisam mostrar evolução ao longo da sprint. Cada sprint acima deve ter pelo menos alguns commits espalhados nos dias, não só no último dia.
- **Cada integrante da equipe precisa ter commits com o próprio usuário GitHub** — quem não aparecer no histórico tira ZERO na entrega, independente do que o time entregou.
- Repositório sempre com README atualizado identificando equipe e projeto (critério de nota, 1,5pt).

## Sobre o drone (SkyVolt)

Fora do caminho crítico das entregas A1/1–A1/3 (o enunciado é explícito: integração com hardware só entra na Unidade 4). Retomar o trabalho de frame/CAD/motor quando a Sprint 11 chegar — até lá, o hardware físico não é avaliado, só o software desktop.

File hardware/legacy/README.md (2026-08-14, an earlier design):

# Legado — frame v1 (peça única)

Primeira versão do chassi, gerada como corpo único (330×290mm). Substituída na Rev. 1.2/1.3 do documento por um design modular de 3 peças (`hardware/frame/`) para caber na mesa de impressão de 220×220mm disponível e para usar o motor brushless RS1606 3300KV real em vez do motor de escova original.

Mantida aqui só como referência histórica — não é a versão a imprimir.

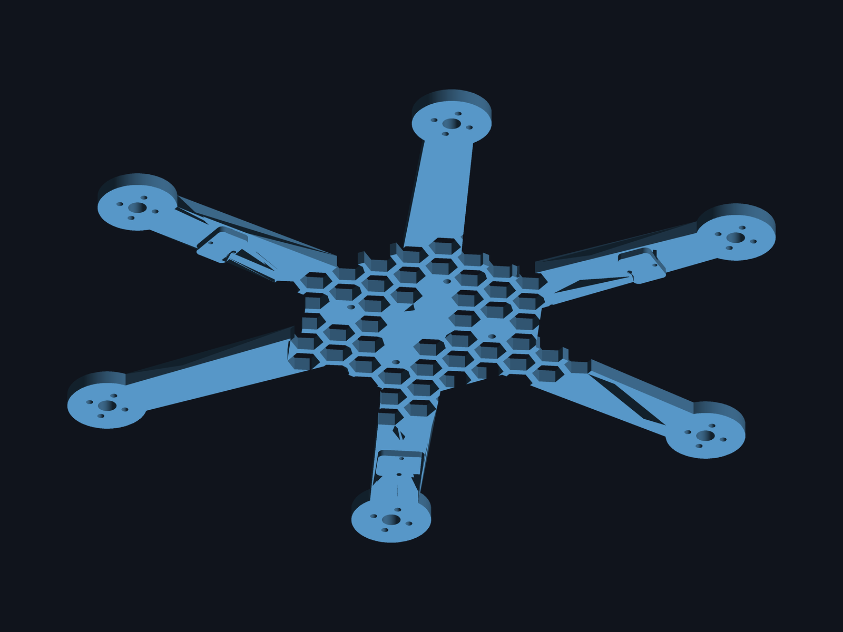
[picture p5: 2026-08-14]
hardware/previews/SkyVolt_Frame_v1_preview.png

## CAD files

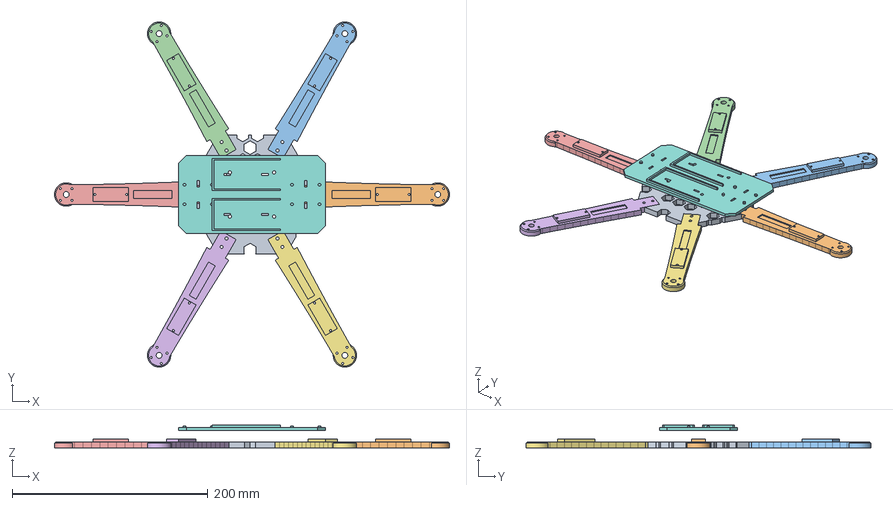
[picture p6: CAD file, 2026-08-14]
hardware/frame/SkyVolt_Assembly_Preview.FCStd
404.0 x 353.1 x 23.4 mm
Hub
Arm_0
Arm_1
Arm_2
Arm_3
Arm_4
Arm_5
Tray

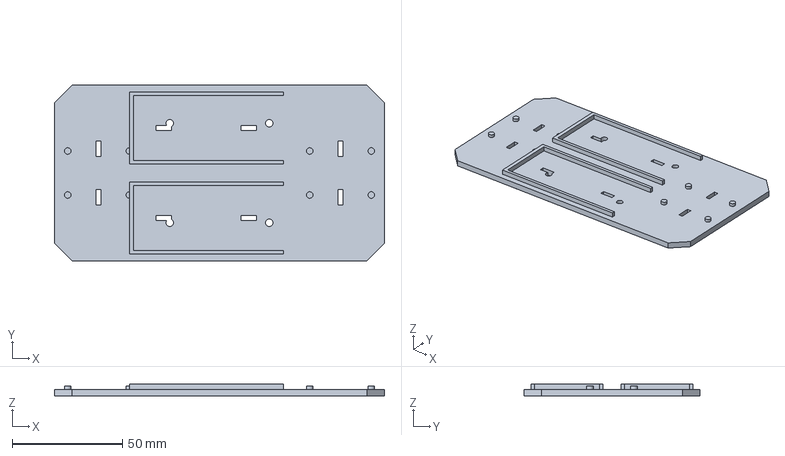
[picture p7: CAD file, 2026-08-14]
hardware/frame/SkyVolt_Tray.step
150.0 x 80.0 x 5.40 mm

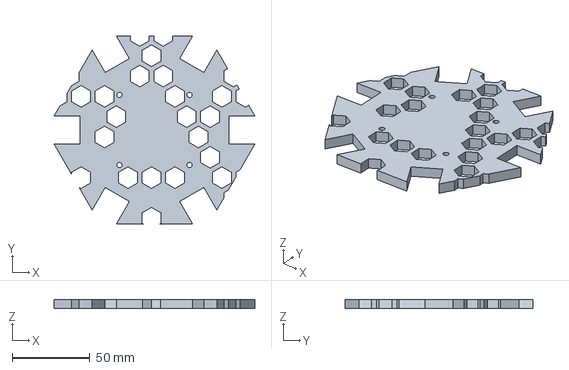
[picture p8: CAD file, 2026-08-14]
hardware/frame/SkyVolt_Hub.step
129.6 x 121.2 x 6.00 mm

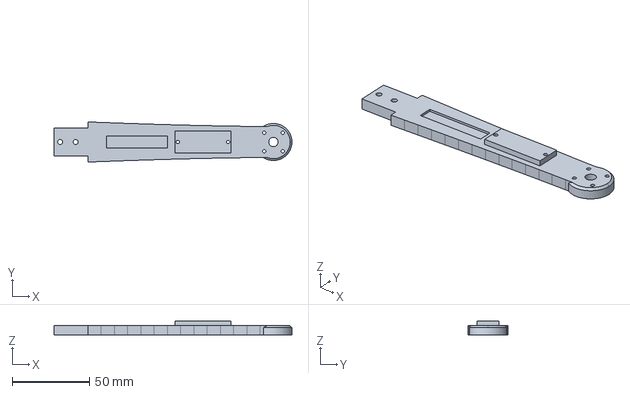
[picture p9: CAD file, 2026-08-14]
hardware/frame/SkyVolt_Arm.step
154.0 x 26.0 x 9.00 mm

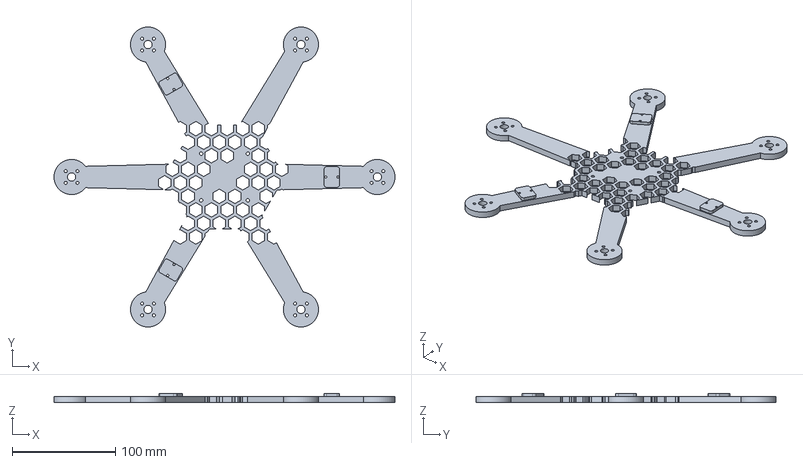
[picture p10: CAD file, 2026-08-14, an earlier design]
hardware/legacy/SkyVolt_Frame_v1.step
330.0 x 290.3 x 9.00 mm

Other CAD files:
hardware/frame/SkyVolt_Arm.FCStd
hardware/frame/SkyVolt_Arm.stl
hardware/frame/SkyVolt_Hub.FCStd
hardware/frame/SkyVolt_Hub.stl
hardware/frame/SkyVolt_Tray.FCStd
hardware/frame/SkyVolt_Tray.stl
hardware/legacy/SkyVolt_Frame_v1.FCStd

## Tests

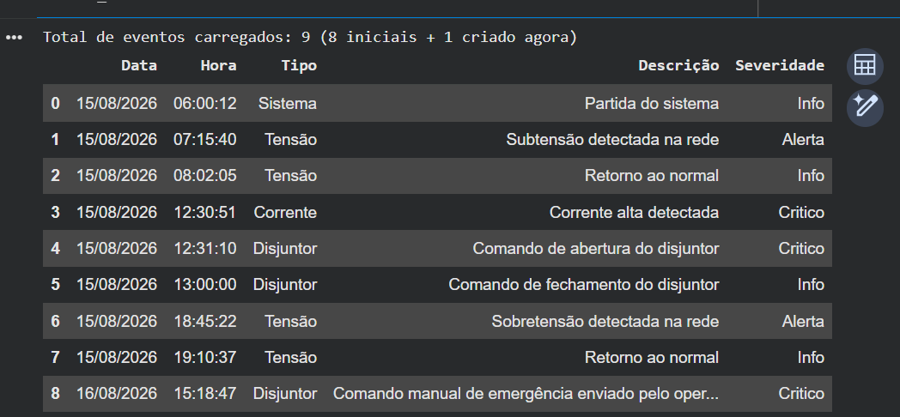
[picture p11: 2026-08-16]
notebooks/Vitória, Testes Colab/Evento.png

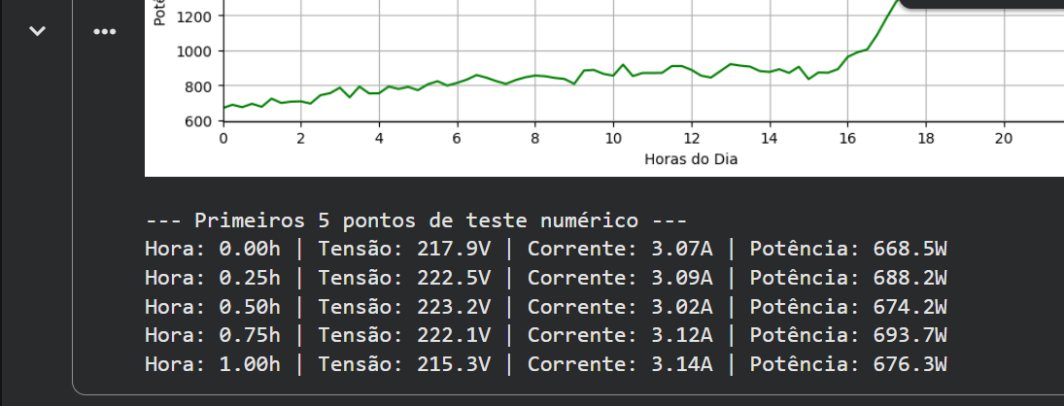
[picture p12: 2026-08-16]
notebooks/Vitória, Testes Colab/Dados_simulados2.png

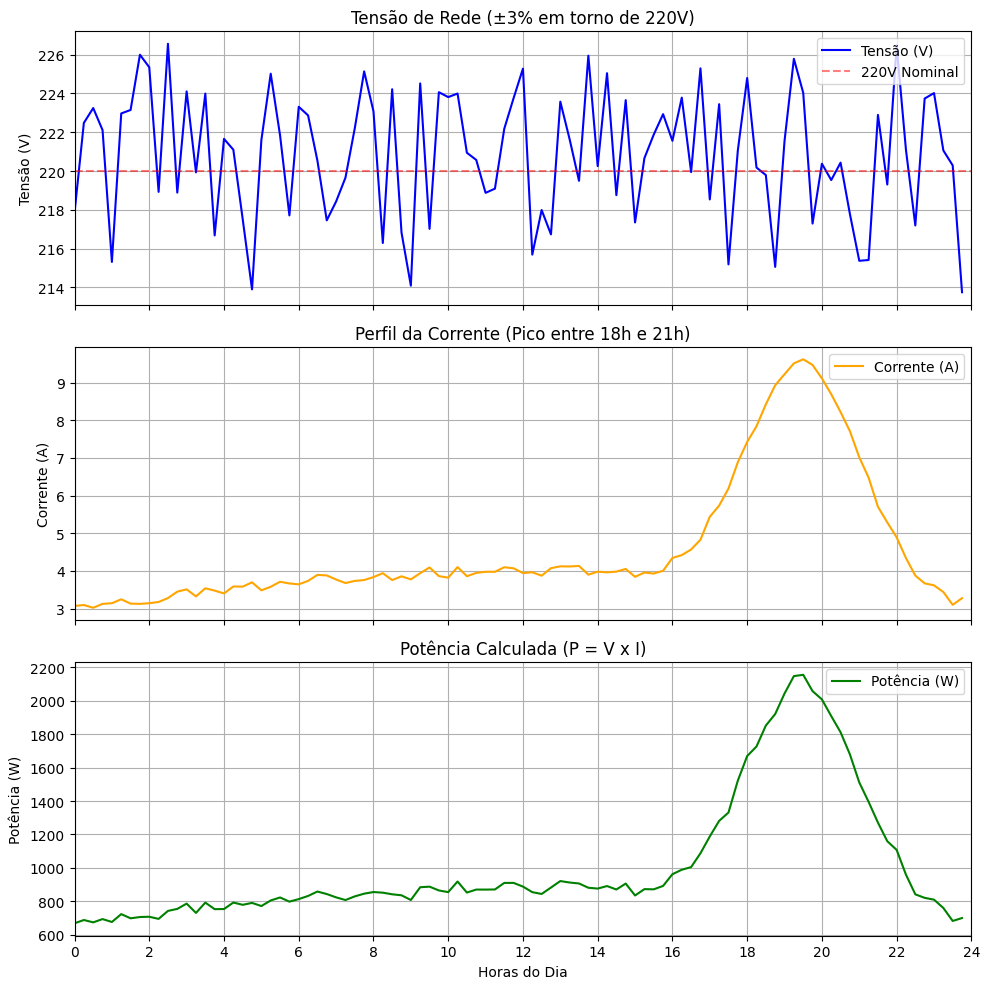
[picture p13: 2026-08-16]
notebooks/Vitória, Testes Colab/Dados_simulados_ImgGrafico.png

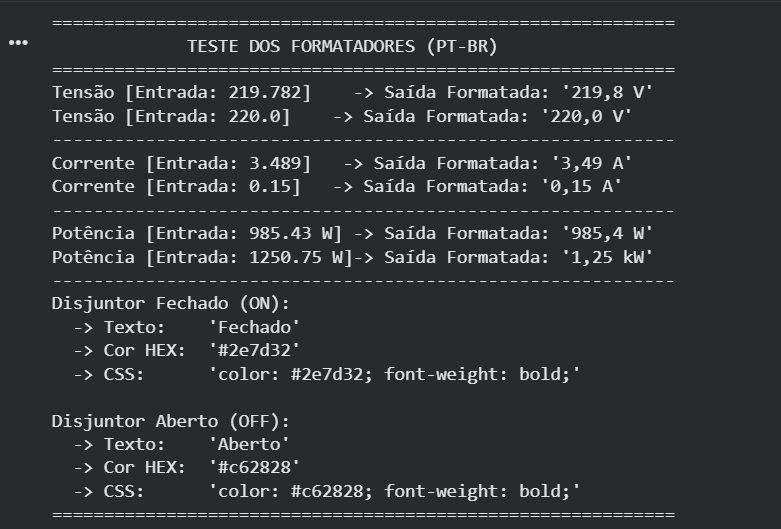
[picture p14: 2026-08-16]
notebooks/Vitória, Testes Colab/formatacao.png

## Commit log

2026-08-14 Initial commit: SkyVolt drone project (Rev. 1.3)
    Requirements/architecture/BOM document, parametric hardware CAD
    (hub + arm x6 + electronics tray, RS1606 3300KV motor), and repo
    scaffolding for firmware, desktop app, notebooks and sprints.
    [SkyVolt_Arm.FCStd, SkyVolt_Arm.step, SkyVolt_Arm.stl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]
2026-08-14 Add preview image gallery to READMEs
    Embed the assembly render as a hero image on the root README and
    a hub/arm/tray gallery on the frame README, so the design is
    visible directly on GitHub without opening the STL files.
2026-08-14 Add sprint_equipe: parallel hardware practice track
    Team-driven track (not graded, doesn't block deliverables) to
    learn hands-on drone assembly: practice kit purchase, soldering,
    firmware flashing, simulator training, and test-fitting the real
    RS1606 motor against the printed arm pad before Unidade 4.
2026-08-14 Add AliExpress links to sprint_equipe shopping list
    Real links found per priority item (practice kit, tools, LiPo
    safety gear, and the RS1606 motor needed to validate the arm's
    bolt pattern), with guidance on trust signals since I can't
    verify seller reliability in real time.
2026-08-15 Rework sprint 1 as objective checklist, add scoped drone track
    Software checklist is now plain objectives (grading weights moved
    to avaliacoes/a1.1.md). Adds a drone-track objectives block sized
    to what actually fits in the 4-day A1/1 window instead of the full
    purchase phase.
2026-08-15 Tie app desktop objectives to SkyVolt's actual telemetry needs
    Adds temperature and AC/DC classification indicators (from
    app/README.md's own spec) alongside the professor's mandatory V/I/P
    and breaker requirements, and reframes the serial panel as the
    future LoRa reception path from the drone's ESP32 #2 instead of a
    generic microcontroller.
2026-08-15 chore(app): scaffolding do pacote app/ e stubs de models (dados_simulados, evento, formatacao)
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2026-08-15 fix(app): main.py chama criar_janela_principal() de main_controller
2026-08-16 Add files via upload
    test: adicionado testes do Colab para validação dos modulos
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2026-08-16 popula histórico de eventos
    Finalizei a implementação dos eventos conforme o Trello #11 e adicionei os 8 registros iniciais de simulação, fiz a função para registrar novos eventos em tempo real usando a hora atual e criei a con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
2026-08-16 adiciona formatadores PT-BR e estilos do disjuntor
    Finalizei as funções de formatação no padrão (com vírgula decimal) para tensão, corrente e potência. Também criei as traduções de status e os estilos visuais em CSS do disjuntor para a interface gráf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
2026-08-16 Fix de interface
    feat(ui): finaliza telas main_window, config_dialog e carrega estilo.qss
2026-08-17 docs(ideias): adiciona divisão de tarefas da Sprint 1 (A1/1)
    Detalha o que cada integrante precisa fazer para fechar o checklist
    da entrega de 17/08, com base no padrão de trabalho por camada MVC
    que o time já vinha seguindo.
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2026-08-17 Adiciona funções de formatação de valores elétricos e estilos para a interface
2026-08-17 Ajuste em modelo de telemetria e lógica de medição
    - Adicionada a classe de dados `LeituraTelemetria` para capturar dados elétricos em tempo real.
    - Criada a função `ler_telemetria` para simular leituras AC (220V) e DC (12V) com variações estatísticas.
    - Implementado o cálculo de potência ativa e validação de sobrecorrente baseada nas configurações.
    - Implementada a rotina de avaliação de qualidade do circuito (Normal, Fora da faixa, Circuito aberto).
2026-08-17 Ajuste de funções no modelo de configuracao do sistema e validacoes
    - Criada a classe `ConfiguracaoSistema` para gerenciar limites de alarme AC/DC, amostragem e corte automático.
    - Implementado o método `esta_dentro_da_faixa` para validação em tempo real de leituras de telemetria.
    - Adicionadas funções utilitárias `configuracao_padrao` e `copiar_configuracao` para isolamento de dados na UI.
    - Adicionada a função `validar_configuracao` com regras estritas para prevenção de inputs inválidos.
2026-08-17 log colorido para o console
    - Adicionada a função `log_evento` para exibição de mensagens com cores ANSI baseadas em severidade (Info, Alerta, Crítico).
    - Criada a função `log_sucesso` com indicador visual verde para marcos concluídos do sistema.
2026-08-17 Update README with new contributor details
    Added contributor information for Sophia Gama de Moura.
2026-08-17 Fix formatting for Sophia Gama de Moura entry
2026-08-25 feat(hardware): adiciona peças Frame e HubLid ao frame modular
    Novas peças geradas em Impressao_3D, ainda pendentes de validação de fit:
    - SkyVolt_Frame.* (FCStd/step/stl)
    - SkyVolt_HubLid.* (FCStd/step/stl) + script skyvolt_hub_lid.py
    - previews de verificação do encaixe (ClampAssembly)
    Não altera skyvolt_frame.py existente (parâmetros da Rev.2 divergem
    do gerador local e precisam de reconciliação manual antes de fundir).
2026-08-25 docs(readme): adiciona galeria das peças novas (Frame, HubLid)
    Referencia as previews já enviadas no commit anterior e sinaliza
    que Frame/HubLid ainda estão pendentes de validação de fit.
2026-08-25 docs(readme): simplifica galeria de peças novas
    Remove o render de verificação do encaixe (não é peça de impressão)
    e adiciona quantidade (1×) para Frame e Hub Lid.
2026-08-25 fix(hardware): move SkyVolt_Frame para legacy (não imprimir)
    Bounding box real confirmado via parsing do STL: 330×290,3×9mm,
    idêntico ao SkyVolt_Frame_v1 legado — não cabe na mesa de 220×220mm.
    Não é peça complementar ao design modular, então sai de hardware/frame/
    (lista de peças a imprimir) e vai para hardware/legacy/ como referência.
    Hub Lid permanece em hardware/frame/, é a única peça nova válida.
2026-09-06 fix(hardware): ajusta pad do motor do braço para A2212 1000kV confirmado
    Furação real medida no motor (16x19mm/4xM3, cana 27,5x27mm, eixo 3,17mm)
    substitui os valores assumidos para RS1606. Braço e assembly regerados
    e conferidos; script pré-A2212 preservado em hardware/legacy/.
2026-10-16 Adicionado estrutura o modulo de banco de dados e cria tabelas de dispositivos, historico e regras
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2026-10-16 implementar gerenciador de logs e funções utilitárias
    • Cria infraestrutura para gravação de logs persistentes em arquivo (smartgrid.log).
    • Adiciona suporte a saída simultânea no terminal/console.
    • Define formatação padrão unificada e funções utilitárias de escopo (log_info, log_warning, log_error).
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2026-10-16 Cria dataclasses de configuração e lógica para salvar/carregar JSON
    • Cria as estruturas ConfiguracaoSistema e ParametrosSerial usando dataclass.
    • Adiciona a função validar_configuracao para checagem preventiva contra valores negativos e inconsistências.
    • Implementa persistência e carregamento automático via config.json com tratamento de falhas e integração com o módulo de logs.
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2026-10-19 Corrigir folga entre hélices citada para o F450 no README
    Com 10", o F450 (450mm na diagonal) deixa ~64mm entre hélices vizinhas,
    não 1–2cm como estava escrito.
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2026-10-19 fix: usa raw f-string no banner para remover SyntaxWarning de escape
2026-10-19 feat(controllers): integra dashboard com SQLite, config.json e corte transacional
    - QTableWidget carregada do banco no showEvent (EventoRepository.listar_todos)
    - novos eventos e alarmes são gravados no SQLite antes de aparecer na tabela
    - Corte Emergencial usa CorteEmergencialService; opção 'Simular falha'
    provoca ROLLBACK e loga [ERROR] ... Rollback executado: <motivo>
    - violação de corrente registrada como [WARNING] no smartgrid.log
    - porta COM, baud rate e timeout lidos de/salvos no config.json
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
